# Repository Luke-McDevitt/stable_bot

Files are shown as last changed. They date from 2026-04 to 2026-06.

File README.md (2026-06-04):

# Stable-Bot 
(https://github.com/Luke-McDevitt/stable_bot)

Stewart-platform ball-balancing system: ROS 2 Kilted nodes + browser GUI
+ vision pipeline. Ships closed-loop click-to-goto control of a ball on
a 6-DOF platform with sub-mm tracking accuracy.

Links to more youtube videos coming soon!
https://youtu.be/bEEpE1CrJFA?si=kh_AgsYBSKObmkfR

## What's here

Three ROS 2 packages:

- **`stewart_bringup`** — main control node (`stewart_control_node`),
  web GUI (`gui_server.py` + `web/index.html`), level-PI inner loop,
  BALL_TRACK closed-loop controller, launch files, deploy scripts,
  digest/comparison tooling.
- **`stewart_vision`** — OAK-D camera driver, ArUco platform-pose
  estimator, parallel ball detectors (cv2 HSV + on-device YOLO),
  Kalman filter, frame-alignment calibration.
- **`jugglebot_interfaces`** — custom message and service types.

Hardware: 6× ODrive Pro motor controllers over CAN, 2× MTi-630 IMUs,
Luxonis OAK-D-PRO-AF camera, Raspberry Pi 5.

## Status

- ✅ **Demo 1 (orbit)** — implemented, tunable
- ✅ **Demo 2 (click-to-goto)** — settled at **0.5 mm median tracking
  error** (bag `20260502T025210Z_demo2`)
- ⚠️ **Demo 3 (path drawing)** — `BALL_TRACK_PATH` is stubbed, returns
  the first waypoint only. Open work.

## Getting started

Clone into a ROS 2 workspace and build:

```bash
cd ~/ros2_ws/src
git clone https://github.com/Luke-McDevitt/stable_bot.git
cd ~/ros2_ws
source /opt/ros/kilted/setup.bash
colcon build --symlink-install \
    --packages-select jugglebot_interfaces stewart_bringup stewart_vision
source install/local_setup.bash
```

Launch (Pi-side, headless):

```bash
sudo systemctl start stable_bot.service stable_bot_gui.service
```

Then open `http://stablebot.local:8080/` in a laptop browser. The
header connection dot turns green within ~5 s; arm, level, and run
demos from the panel.

For laptop / dev workflow, see
[`PI_MIGRATION.md`](stewart_bringup/docs/PI_MIGRATION.md).

## Running on the Pi — SSH & startup

**🌐 Web GUI (open in your browser):** **http://stablebot.local:8080/**
The control panel — arm, level, run demos. IP fallback:
`http://10.86.11.98:8080/`. Prefer the `.local` name; on the phone hotspot
the IP changes each session.

> **Both the laptop and the Pi must be on the same network** (your phone
> hotspot). If the GUI won't load or SSH times out, that's almost always
> the cause — reconnect both to the hotspot.

**Pi login:** user `sorak` · hostname `stablebot`

```bash
ssh sorak@stablebot.local      # preferred — mDNS resolves the current IP
ssh sorak@<current-ip>         # e.g. 10.86.11.98; changes on the hotspot
```

**Pi IP:** `10.86.11.98` (last seen). On the phone hotspot this changes
each session, so prefer `stablebot.local`. Need the current IP? Run
`hostname -I` **on the Pi** (the SSH login *banner* caches a stale IP —
ignore it; trust `hostname -I`).

**GUI rosbridge connection:** the header connection box now **auto-targets
the host you opened the page from** (`ws://<that-host>:9090`), so opening
`http://stablebot.local:8080/` connects with no IP to type. If the dot
stays red, the box is editable — set it to `ws://<current-ip>:9090`
(e.g. `ws://10.86.11.98:9090`) and click **Reconnect rosbridge**.

**Startup is two systemd services** (auto-start on boot — this *is* the
"startup script"):

| Service | What it runs |
|---|---|
| `stable_bot.service` | the ROS 2 control stack (`stewart_control_node` + vision nodes), via `ros2 launch stewart_bringup stewart_gui_launch.py` |
| `stable_bot_gui.service` | the web GUI server (`scripts/gui_server.py`) on `:8080` |

Both unit files live in [`stewart_bringup/scripts/`](stewart_bringup/scripts/)
(`stable_bot.service`, `stable_bot_gui.service`). First-time setup installs
and enables them; deploys refresh them:

```bash
# one-time, on a fresh Pi (installs deps, udev, CAN, services):
bash ~/ros2_ws/src/stable_bot/stewart_bringup/scripts/install_on_pi.sh

# deploy code changes (pull → build → restart both services → verify SHA):
~/stable_bot_repo/stewart_bringup/scripts/pi_deploy.sh
```

Day-to-day, over SSH:

```bash
sudo systemctl status  stable_bot stable_bot_gui     # are they up?
sudo systemctl restart stable_bot stable_bot_gui     # restart both
journalctl -u stable_bot.service -f                  # follow control-stack logs
journalctl -u stable_bot_gui.service -f              # follow GUI logs
```

Then open `http://stablebot.local:8080/` (or `http://10.86.11.98:8080/`)
in a laptop browser.

## Documentation

### How it works

- [`ARCHITECTURE.md`](stewart_bringup/docs/ARCHITECTURE.md) — how the
  nodes, topics, and services fit together.
- [`closed_loop_ball_demos.md`](stewart_bringup/docs/closed_loop_ball_demos.md)
  — design spec for the three demos (vision, ArUco markers, ball
  detection, KF, controllers, GUI).
- [`closed_loop_ball_demos_usage.md`](stewart_bringup/docs/closed_loop_ball_demos_usage.md)
  — operator guide: cold start, calibration, running each demo, safety.
- [`level_loop_architecture.md`](stewart_bringup/docs/level_loop_architecture.md)
  — inner level-PI loop design.

### How it got here

The journey docs are read end-to-end if you're going to touch the
controls or vision code; they explain *why* every architectural
choice was made.

- [`controls_journey.md`](stewart_bringup/docs/controls_journey.md)
  — vision rate fixes, ArUco↔IMU frame alignment, sign-convention
  derivation (2026-04-30).
- [`vision_control_tuning_lessons.md`](stewart_bringup/docs/vision_control_tuning_lessons.md)
  — vision pipeline lessons + controller architecture changes
  (2026-04-30).
- [`step_id_tuning_lessons.md`](stewart_bringup/docs/step_id_tuning_lessons.md)
  — STEP_ID plant identification, two-tilt-thresholds insight,
  cascade-bypass decision (2026-05-01).
- [`level_loop_lessons_learned.md`](stewart_bringup/docs/level_loop_lessons_learned.md)
  — runtime-vs-persistent CAN state, empirical Jacobian discovery
  (2026-04-27 → 2026-04-29).
- [`demo2_shipping_journey_2026-05-02.md`](stewart_bringup/docs/demo2_shipping_journey_2026-05-02.md)
  — the day Demo 2 shipped: empirical IK in BALL_TRACK, stiction ramp,
  position-delta exit, the winning gain set.

### Compiled cheat sheet

- [**`LESSONS.md`**](stewart_bringup/docs/LESSONS.md) — every durable
  rule from the journey docs in one terse compilation. Organized by
  topic (ODrive, vision, frames/IK, control theory, stiction, tooling,
  things that didn't work). Read this if you have 10 minutes and want
  the executive summary.

### Reference

- [`ODRIVE_PARAMS.md`](stewart_bringup/docs/ODRIVE_PARAMS.md) — every
  ODrive parameter we set, why, and the runtime-vs-persistent path.
- [`REFLASH_FIRMWARE.md`](stewart_bringup/docs/REFLASH_FIRMWARE.md) —
  ODrive firmware update procedure.
- [`PI_MIGRATION.md`](stewart_bringup/docs/PI_MIGRATION.md) — Pi 5
  headless install, hotspot setup, gotchas (apt sources, arm64
  Xsens rebuild, two-services pattern).
- [`TROUBLESHOOTING.md`](stewart_bringup/docs/TROUBLESHOOTING.md) —
  recovery recipes for rosbridge / CAN / IMU issues.
- [`NEXT_STEPS.md`](stewart_bringup/docs/NEXT_STEPS.md) — roadmap from
  the early scripted-rolling-ball state.

### Vision, latency & roadmap (2026-06 work)

- [`control_path_latency.md`](stewart_bringup/docs/control_path_latency.md)
  — **end-to-end latency trace, detection → platform moved**, every stage
  grounded in code with a **value-provenance table** (where each gain/limit
  lives). Read this to know where a number comes from.
- [`oak_latency_map.md`](stewart_bringup/docs/oak_latency_map.md) —
  vision-side latency sources + the control-path-vs-GUI-display distinction.
- [`oak_highspeed_detection_analysis.md`](stewart_bringup/docs/oak_highspeed_detection_analysis.md)
  — camera config, the focus/exposure work, and what's adopted (focus 130,
  exposure 1500 µs/ISO 3200).
- [`oak_focus_exposure_autocal.md`](stewart_bringup/docs/oak_focus_exposure_autocal.md)
  — empirical focus/exposure calibration method (the sweeps + metrics).
- [`oak_on_device_detection_research.md`](stewart_bringup/docs/oak_on_device_detection_research.md)
  — on-device detection options (YOLO re-test / fixed color blob).
- [`ball_physics_modeling_plan.md`](stewart_bringup/docs/ball_physics_modeling_plan.md)
  — data-driven ball+platform model to replace the constant-velocity
  look-forward (the next major controls project).
- [`IMPLEMENTATION_PLAN.md`](stewart_bringup/docs/IMPLEMENTATION_PLAN.md)
  — how the GUI/deploy/data-collection pieces fit together.

## Tooling

In `stewart_bringup/scripts/`:

| script | purpose |
|---|---|
| `pi_deploy.sh` | full Pi deploy: pull, colcon-build the right packages, restart both services. |
| `digest_demo_bag.py` | post-process a Demo 2/3 bag → digest.png + digest.summary.json + next-step gain recommendation. |
| `digest_step_id_bag.py` | post-process a STEP_ID bag → plant gain G_eff fit + analytic Kp/Kd/Ki recommendation. |
| `compare_demo_bags.py` | walk every digest.summary.json across a bag glob, sortable table of gains vs outcome metrics. `--diff` collapses to only the columns that varied. |
| `smooth_demo_bag.py` | offline non-causal Savitzky-Golay smoother on raw vision detections. Outputs cleaner ground-truth velocity than the live causal KF. Suitable as ML training labels. |
| `calibrate_oak.py` | OAK intrinsic + extrinsic calibration (Stage A / B / C). |

In `stewart_vision/scripts/` (focus/exposure auto-calibration — see
[`oak_focus_exposure_autocal.md`](stewart_bringup/docs/oak_focus_exposure_autocal.md)):

| script | purpose |
|---|---|
| `focus_exposure_baseline.py` | **observe-only** — snapshot the current camera config + sharpness/exposure metrics to `tuning_data/<UTC>_baseline/`. The don't-make-it-worse reference. |
| `focus_sweep.py` | step the lens through focus, measure sharpness (Tenengrad / Laplacian) per position, find the peak; **restores original focus on exit**. Repeat per `--z-mm` to build the Z→focus map. |

Top-level `repo_loc.py` counts lines of code per language across the
repo.

## Hardware reference

| Component | Detail |
|---|---|
| MCUs | 6× ODrive Pro on CAN bus (gs_usb adapter, VID:PID 1d50:606f) |
| IMUs | 2× MTi-630 over USB serial (`/dev/imu_mti630`, `/dev/imu_mti630_b`), 921600 baud, 400 Hz |
| Camera | Luxonis OAK-D-PRO-AF, USB-3 SuperSpeed, mounted on overhead arm |
| Compute | Raspberry Pi 5 (16 GB), Ubuntu 24.04, ROS 2 Kilted |
| Markers | ArUco DICT_4X4_50, 8 markers on a 120 mm-radius ring on the platform |

## Project layout

```
stable_bot/
  README.md                          ← you are here
  repo_loc.py                        ← lines-of-code counter
  jugglebot_interfaces/              ← custom msg/srv types
  stewart_bringup/
    config/
      ball_track_gains.yaml          ← BALL_TRACK PID + stiction-ramp gains
      level_gains.yaml               ← level-PI gains
      leg_limits.yaml                ← per-leg soft-limits in turns
      global_limits.yaml             ← hard tilt-rate caps
    docs/                            ← architecture + journey + lessons
    launch/                          ← stewart_gui_launch.py
    scripts/
      pi_deploy.sh                   ← deploy
      stable_bot.service             ← systemd unit (control stack)
      stable_bot_gui.service         ← systemd unit (web GUI)
      digest_demo_bag.py             ← per-bag analysis
      compare_demo_bags.py           ← cross-bag comparison
      smooth_demo_bag.py             ← offline smoother
    stewart_bringup/
      stewart_control_node.py        ← main control node (~5500 lines)
      auto_tune_node.py              ← (legacy) hill-climb auto-tuner
    web/index.html                   ← single-file Tailwind+roslibjs GUI
  stewart_vision/
    stewart_vision/
      oak_driver_node.py             ← OAK pipeline + on-device detectors
      ball_localizer_node.py         ← pixel → platform-frame mm + ArUco→IMU rotation
      ball_kf_node.py                ← Kalman filter on ball position
      platform_pose_node.py          ← ArUco-board pose
      ref_generator_node.py          ← demo target trajectories
    config/
      aruco_imu_alignment.yaml       ← Procrustes-fit rotation
      marker_layout.yaml             ← ArUco board geometry
      oak_extrinsics.yaml            ← camera-to-platform calibration
    blobs/                           ← compiled neural-net detectors for the OAK VPU
    scripts/
      calibrate_oak.py
      build_v0_blob.py
  tuning_data/                       ← bag dirs + digests, committed for traceability
  training_data/                     ← YOLO labels + cached metadata (gitignored bulk)
```

## Contributing / future work

Open work, in roughly priority order:

1. **Demo 3 (path drawing)** — implement `BALL_TRACK_PATH` ref
   generator (arc-length traversal at speed). ~30-line implementation
   per the spec.
2. **Live KF Q/R re-tuning** — use offline-smoother truth from
   `smooth_demo_bag.py` as ground truth for a Q/R grid search.
3. **Learned ball-state filter** — train a small RNN on (raw vision +
   IMU) → (smoothed position, velocity), where targets come from the
   offline smoother. Replaces or augments the live KF.
4. **End-to-end latency measurement** — automated digest analyzer
   that times from V0 detection to motor response. Lets us tune
   `control_latency_s` empirically per-config.
5. **Vision noise mitigation at the source** — better lighting,
   shorter exposure, ball-surface texture. Biggest single physical
   improvement, no code.

## License

GNU General Public License (GPL) v3

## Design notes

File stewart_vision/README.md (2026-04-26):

# stewart_vision

Vision pipeline for the Stable-Bot Stewart platform.

This package implements the OAK-D Pro AF driver, ArUco-ring platform
pose recovery, ball localization (mono projection + stereo
triangulation), the Kalman tracker, and the reference generators for
the three closed-loop ball demos defined in
`../stewart_bringup/docs/closed_loop_ball_demos.md`.

The package is **kept separate from `stewart_bringup`** so that anyone
wanting a different vision stack (RealSense, mocap, mono webcam, …)
can swap this package out without touching the controller. Topics are
the contract; node implementations are interchangeable.

## Status

**v0.1 — scaffold.** Package builds and nodes run, but most algorithm
implementations are stubs marked with TODO. The OAK driver
(`oak_driver_node`) is the most fleshed-out node and is wired against
real DepthAI for the OAK-D Pro AF.

## Build

From your colcon workspace root (the repo expected to be checked out
under `<ws>/src/stable_bot_repo`):

```bash
source /opt/ros/kilted/setup.bash
colcon build --packages-select stewart_vision
source install/local_setup.bash
```

## Run

```bash
ros2 launch stewart_vision stewart_vision_launch.py
```

Or run nodes individually:

```bash
ros2 run stewart_vision oak_driver_node
ros2 run stewart_vision platform_pose_node
ros2 run stewart_vision ball_localizer_node
ros2 run stewart_vision ball_kf_node
ros2 run stewart_vision ref_generator_node
```

## Calibration

```bash
python3 scripts/calibrate_oak.py --stage all  # first time
python3 scripts/calibrate_oak.py --stage C    # after every camera move
```

See §6 of the spec for stages A/B/C details.

## Layout

```
stewart_vision/
├── stewart_vision/         # ROS 2 nodes (Python)
├── scripts/                # Calibration + dataset + plotting tools
├── config/                 # marker_layout.yaml, ball_safety.yaml, intrinsics
├── launch/                 # stewart_vision_launch.py
└── docs/                   # README; spec lives in stewart_bringup/docs/
```

## Hardware target

Luxonis OAK-D Pro AF (auto-focus IMX378 RGB + dual OV9282 stereo monos
+ IR projector + IR illumination + Movidius Myriad X VPU). DepthAI
≥ 2.24 expected. The driver should also work on plain OAK-D and OAK-D
Pro (fixed-focus) without changes — auto-focus controls are conditional.

## Dependencies (Python)

- `depthai` ≥ 2.24 (OAK device API)
- `opencv-contrib-python` (ArUco lives in contrib)
- `numpy`
- `cv_bridge` (ROS 2 ↔ OpenCV)
- `PyYAML`

Install via apt where possible (`ros-kilted-cv-bridge`); pip the rest.

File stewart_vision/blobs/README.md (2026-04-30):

# OAK on-device V0 blobs (Phase 2B)

This directory holds compiled `.blob` files for the OAK-D Pro AF's
Myriad X VPU. They replace the host-side cv2 HSV+contour V0 detector
with on-device inference, dropping per-detection USB load from ~1.5 MB
(raw frame) to ~16 B (NNData with three FP16 floats).

## Building

The blob isn't built automatically — `blobconverter` is a Luxonis
cloud service that needs internet, and the Pi may not have torch
installed. Build from a dev machine:

```bash
pip install torch onnx blobconverter
cd ~/stable_bot_repo
python stewart_vision/scripts/build_v0_blob.py
```

That writes `stewart_vision/blobs/v0_320x180.blob`. Commit it:

```bash
git add stewart_vision/blobs/v0_320x180.blob
git commit -m "blob: rebuild V0 NN (color weights ...)"
git push
```

Then on the Pi:

```bash
~/stable_bot_repo/stewart_bringup/scripts/pi_deploy.sh
```

## Activating

The OAK driver picks `cv2` (the host detector) by default. To switch
to the NN backend, set `OAK_V0_BACKEND=nn` in the systemd override:

```bash
sudo systemctl edit stable_bot.service
```
Add:
```
[Service]
Environment=OAK_V0_BACKEND=nn
```
Save, then `sudo systemctl restart stable_bot.service`.

The `[boot]` log will show which backend was selected. If you ask
for `nn` but the blob isn't found at startup, the driver falls back
to `cv2` and logs a warning — your demos won't break.

## Tuning

Edit the color-score weights in `scripts/build_v0_blob.py` and rebuild.
The current defaults are tuned for saturated orange foam ball under
the headlamp / IKEA-panel lighting. If you change ball color or
lighting drastically:

- High-R, low-B objects: keep current weights, raise `BIAS`.
- Different hue (e.g., red vs orange vs yellow): adjust `W_G` upward
  for yellow-ish, downward for redder.
- More motion blur tolerance: lower `SCORE_FLOOR` (lets dimmer
  pixels contribute to the centroid; risk: false positives).

After rebuilding, the OAK driver picks up the new blob on next
restart — no Python source change required.

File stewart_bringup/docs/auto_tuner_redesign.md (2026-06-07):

# Auto-tuner redesign — post-mortem + ideal design

**Purpose.** We have two abandoned tuning systems (STEP-ID and the hill-climb
auto-tuner) and went back to hand-tuning. This document (1) explains what each
was, how it was used, and **why both failed**, (2) surveys what researchers
actually do, and (3) specifies the auto-tuner I'd build from scratch — with
every edge case, the integration, the accept/revert logic, the GUI sync, and
how it uses the digest to *diagnose* rather than blindly search.

Read alongside `step_id_tuning_lessons.md` and `vision_control_tuning_lessons.md`
(the primary sources) and `auto_tuning_plan.md` (the original hill-climb plan).

---

## Part 1 — Post-mortem: what they were and why both failed

### They are two fundamentally different philosophies

| | **STEP-ID** | **Hill-climb auto-tuner** |
|---|---|---|
| Philosophy | **Model-based** (white-box) | **Model-free** (black-box) |
| What it measures | Plant gain `G_eff` from open-loop tilt-step tests | A closed-loop *fitness* score per demo trial |
| How it picks gains | **Analytic** — pole-placement formula `Kp = ωn²/G_eff`, `Kd = 2ζωn/G_eff` | **Search** — perturb a gain, keep it if fitness improved |
| Targets | Repeatable fixed steps (92 mm / 170 mm) | Fixed-distance **random-direction** gotos |
| Output | One Kp/Kd/Ki recommendation | A best-found gain vector after N trials |

STEP-ID asks *"what is the plant, so I can compute the right gains?"* The
auto-tuner asks *"which gains score best, never mind why?"* They are the two
canonical families (system-identification vs derivative-free optimization).

### Why STEP-ID failed: the plant measurement isn't repeatable

`G_eff` measured **6 times in one evening on identical hardware came out 35,
224, 92, 64, 148, 564** — a 5–10× spread on an in-principle-deterministic
number. The analytic gains are a *direct function* of `G_eff`, so garbage in →
garbage out: one fit's `Kp=0.077` "drove the ball into orbital limit cycle every
trial." Three generations of the fit (parabolic → peak-velocity → regression of
`v` vs `∫θ`) only reached **30–50% CV**. The root cause was **vision noise** —
single-frame detector false-positives spiking velocity to **4,500–5,500 mm/s**
on a ball that physically tops out ~800. A single-point identification can't
average that out.

### Why the auto-tuner failed: it can't tell bad gains from bad vision

The hill-climb ran (the `auto_tune_*` sessions exist) but never beat hand-tuning.
Its documented core risk: *"Vision instability poisons fitness scores. The
auto-tuner can't separate 'bad gains' from 'bad vision'."* Concretely:
- **Random-direction targets** mean every trial has different difficulty and a
  different interaction with the vision noise → the fitness signal is buried in
  trial-to-trial variance.
- **Greedy accept/reject on a single noisy trial** (a `noise_floor` band-aid)
  means the search wanders — it accepts lucky-vision trials and rejects good
  gains that drew an unlucky trial.
- **A scalar fitness with no diagnosis** — it knows trial 12 scored 0.6, but not
  *why* (over-damped? orbiting? steady-state offset?), so it can't move
  intelligently; it perturbs blindly.
- **A pre-flight frame/alignment blocker** (§0 of the plan: "click never matches
  tilt direction") — tuning on a wrong frame just finds gains that minimize
  wrong-direction error.

### The single shared root cause

**Both failed at the *evaluation*, not the *optimizer*.** A noisy, non-repeatable,
single-shot evaluation defeats *any* tuning method — model-based or model-free.
STEP-ID's noisy evaluation was `G_eff`; the auto-tuner's was the fitness score.
Fix the evaluation and either method can work; leave it broken and neither can.

**What changed since (the board is different now):**
- **Pi under-voltage throttling is fixed** (the BEC back-feed — see
  `pi_power_throttling.md`). The Pi was likely throttling *mid-trial* during
  those sessions → dropped vision frames + timing jitter = exactly the
  non-repeatability that poisoned both. The old sessions never had this fixed.
- **The #1 documented "should-try-next" was never done: tune the KF `R`.** The
  meas-noise data now exists (`R ≈ 0.2 mm`) to dampen the velocity spikes at the
  source.
- **We now have rich step-response metrics** (overshoot / ITAE / settle / path)
  and a **validated physics model** that can serve as a digital twin.

---

## Part 2 — What researchers actually do

Three families, in rough order of sophistication:

1. **Relay feedback (Åström–Hägglund).** Replace the controller with an on/off
   relay; the loop limit-cycles at the plant's critical frequency; read the
   ultimate gain `Ku` and period `Tu` from the oscillation and apply tuning
   rules. *"One of the simplest and most robust auto-tuning techniques… applied
   in industry for 15+ years… no preliminary experiments, modeling, or external
   tools."* Strength: one short, self-exciting experiment. Weakness for us: it
   measures *one* operating point and assumes a fairly linear plant — our plant
   has stiction + the two-tilt-threshold nonlinearity.

2. **Bayesian Optimization (the modern default for expensive/noisy tuning).**
   Fit a **Gaussian-process surrogate** to the (gains → score) data seen so far,
   then pick the next gains by maximizing an **acquisition function** (expected
   improvement). It is built for *"expensive and noisy black-box optimization"* —
   the GP explicitly models observation noise, so it doesn't chase lucky trials.
   Key variants directly relevant to us:
   - **Safe / constrained BO (SafeOpt)** — restrict evaluations to a region
     that's probabilistically *stable/safe*, so the optimizer never proposes
     gains likely to send the ball orbiting.
   - **Risk-averse BO under heteroscedastic noise** (e.g. RaGoOSE) — for when
     the noise itself varies with the gains (ours does: bad gains → fast ball →
     worse vision).
   - **Early-stopping BO** — abort a clearly-bad trial early to save time.
   - **Digital-twin BO** — explore on a *model* first, spend real trials only
     where the model is uncertain. **We have a model.**

3. **Iterative/data-driven tuning (IFT, VRFT).** Estimate the gradient of a
   closed-loop cost directly from experiment data and step the gains. Powerful
   but needs cleaner signals than we have today.

**The unanimous theme:** the optimizer matters less than (a) **replicated,
low-variance evaluation**, (b) **a noise-aware surrogate** so single trials don't
mislead, and (c) **explicit safety constraints**.

Sources: [Safe contextual BO for PID tuning](https://arxiv.org/pdf/1906.12086) ·
[Safe risk-averse BO for controller tuning](https://www.researchgate.net/publication/371855392_Safe_Risk-averse_Bayesian_Optimization_for_Controller_Tuning) ·
[Early-stopping BO for controller tuning](https://arxiv.org/pdf/2501.11532) ·
[Constrained BO for cascade controller tuning](https://www.researchgate.net/publication/359250332_Safety-Aware_Cascade_Controller_Tuning_Using_Constrained_Bayesian_Optimization) ·
[Relay feedback auto-tuning — tutorial review](https://www.sciencedirect.com/science/article/abs/pii/S0959152401000257) ·
[Relay auto-tuning via iterative feedback tuning](https://www.sciencedirect.com/science/article/abs/pii/S0005109802002017)

---

## Part 3 — The ideal auto-tuner

Seven principles, each fixing a specific failure above.

### P1. Repeatable evaluation — auto-ferry to a fixed start, fixed target
*(fixes the random-target variance; finishes what STEP-ID started with "repeatable
start/end points")*

The single biggest lever. Every trial must be **identical** so the only variable
is the gains:
- **Auto-ferry**: between trials, switch to the **champion** gain set and drive
  the ball to a canonical **start** position; confirm it's settled within a
  tight band (`|err| < 8 mm`, `|v| < 20 mm/s` for 1 s) before the trial begins.
  This removes manual ball placement — the thing the operator was doing by hand
  for the model A/B — as a variance source.
- **Fixed target**: send to the **same** target each trial (the operator's
  place-and-send move, automated). Use a **small panel of 2–4 canned moves**
  (e.g. 90 mm and 170 mm, two directions) so we tune for more than one operating
  point, but each *specific* move is repeated identically.
- **Verify the start** before scoring; if the ferry didn't land the ball in the
  band, re-ferry once, else mark the trial **invalid** (not "bad").

### P2. Statistical decision — replicate, gate on CV, accept only beyond noise
*(fixes single-shot accept/reject)*

- Each gain set is evaluated with **N≥3 replicates** of each canned move.
- Compute the objective's **median and spread** across replicates. If the
  **coefficient of variation exceeds a gate (CV > 0.30)** — STEP-ID's own rule —
  **refuse to decide**: collect more replicates or flag the run as
  vision-limited. A noisy evaluation is a *measurement failure*, not a gain
  verdict.
- A challenger only beats the champion if its objective is better by **more than
  the pooled noise** (a one-sided test on the replicate distributions, not a
  single number). This is exactly what BO's noise model does automatically.

### P3. A diagnostic objective, not a blind scalar — *use the digest to know what to change*
*(fixes "can't tell why a gain set is bad"; answers "use bag digest data to be
more educated")*

We now have per-goto **step metrics** (`overshoot_pct`, `rise_s`, `settle_s`,
`steady_state_err_mm`, `settled_rms_mm`, lateral/path, `reversals`, `IAE/ITAE`).
Use them two ways:

1. **As the objective** — minimize **ITAE** (the textbook single-number step
   quality, penalizes lingering error) with **overshoot and settle as
   constraints** (e.g. "minimize ITAE subject to overshoot ≤ 20%"). Far better
   signal than the old rms/hold/calm blend.
2. **As a diagnosis that *guides* the search** — map symptoms → moves the way a
   human expert does, to give the optimizer an informed prior:

   | digest symptom | likely cause | suggested move |
   |---|---|---|
   | high overshoot, oscillatory, ITAE high | under-damped | ↑ Kd, or ↓ Kp |
   | slow rise, sluggish, never overshoots | over-damped / weak | ↑ Kp |
   | settles with a constant offset (`steady_state_err`) | no integral authority | ↑ Ki |
   | orbital limit cycle, persists regardless | `max_tilt < θ_orb` **or** vision noise | ↑ max_tilt to `max(θ_s+2.5, 8)`; check vision |
   | ball never leaves start | `Kp·err < θ_s` (stiction) | ↑ Kp / ↑ max_tilt / stiction relief |
   | large lateral wander, wrong-direction error | frame/sign/alignment | **stop** — not a gain problem |
   | `settled_rms` high but mean ~0 | vision velocity noise | tune KF `R`, not gains |

   The optimizer (BO) does the fine search; the diagnosis table provides the
   *initial direction* and catches non-gain problems (frame, vision) so we don't
   waste trials "tuning" something gains can't fix.

### P4. Noise-aware, sample-efficient optimizer — Bayesian optimization
*(replaces greedy hill-climb)*

Fit a GP to `(gain_vector → objective)` with an explicit **noise term** equal to
the measured replicate variance, and choose the next gains by **expected
improvement**. This is the documented modern standard for noisy black-box
controller tuning and is far more sample-efficient than hill-climbing (which we
can't afford many trials of). Seed it with the diagnosis-table direction from P3
and the current champion. `scikit-optimize`/`BoTorch` provide this; if we can't
put them on the Pi, run the BO step **off-board** (the Pi only runs trials and
streams results) — the optimization is cheap, the trials are the expense.

### P5. Safety — bounded, stability-screened, vision-gated, always-revertible
*(fixes "could try unstable gains"; the operator's safety bar)*

- **Hard gain bounds**, clamped before any apply.
- **Constrained/safe BO**: never *propose* gains the surrogate predicts are
  unstable (orbital). Treat "ball escaped / violent oscillation" as a **safety
  constraint violation**, recorded so that region is avoided — not just a low
  score.
- **Vision-health gate** before/within each trial: check `vcgencmd
  get_throttled == 0x0`, `/oak/health` rate, and `/ball_state` freshness. A
  trial run under throttling or a vision dropout is **invalid**, not scored.
- **Early-abort** a trial the instant the ball escapes the ring, the error
  *grows* after the goto (sign/instability), or a time budget is hit → command
  LEVEL_HOLD, ferry back.
- **Foam ring + operator kill button** (instant LEVEL_HOLD + `abort=true`) +
  **auto-halt** on K consecutive invalid/sub-floor trials.

### P6. The physics model as a digital twin — pre-screen in sim
*(uniquely available to us now)*

Before spending a *real* trial on a proposed gain set, **simulate** the move with
the fitted `ball_model.yaml` + the controller, and reject anything that's clearly
unstable or much worse than the champion in sim. This (a) keeps the ball safe
(never run a predicted-orbital gain on hardware), and (b) multiplies sample
efficiency — the documented "digital-twin BO" idea. The twin won't be exact
(that's why we still validate on hardware), but it's an excellent **safety and
triage filter**.

### P7. Champion–challenger with full provenance and atomic apply
*(answers accept / revert / GUI-update)*

- A **champion** gain set is always the current best *validated* set. A
  **challenger** must beat it on a **held-out verification panel** (canned moves
  *not* used during the search), replicated, beyond noise, **and** pass the sim
  screen, to be **promoted**.
- **Apply is atomic**: promotion calls the existing `set_control_gains` (writes
  `ball_track_gains.yaml` + updates the live dict), which already rides
  `/status` so **the GUI Gains panel inputs auto-populate** — no second code
  path. (Same mechanism that now syncs the control-method dropdown.)
- **Revert is trivial and total**: every gain set + its full metric distribution
  is logged to `tuning_data/auto_tune_<UTC>/log.jsonl`; the champion before the
  session is saved; a **"Revert to champion"** GUI button re-applies it; and
  because the yaml is git-tracked, `git checkout` is the ultimate undo. Nothing
  is overwritten without the prior value preserved.

---

## Part 4 — Every edge case

| # | Edge case | Detection | Handling |
|---|---|---|---|
| 1 | Ball escapes the ring | `/ball_state` stale > 0.5 s, or `|pos| > R` | abort trial → **invalid**, LEVEL_HOLD, ferry, retry once |
| 2 | Vision dropout mid-trial | `/ball_state` gap, `/oak/health` rate low | mark trial **invalid** (not scored); pause if persistent |
| 3 | Pi throttling during trial | `get_throttled != 0x0` | **invalid**; pause session, surface alert (should be rare post-BEC-fix) |
| 4 | Ferry fails to seat the ball at start | start band not met after re-ferry | **invalid** trial; if repeated, halt — likely champion can't hold |
| 5 | Ball never leaves start (stiction) | `max(progress) < min_travel` over the move | score = worst-feasible **with** diagnosis "below stiction"; informs ↑Kp/↑max_tilt |
| 6 | Orbital limit cycle | sustained `reversals`/speed, never settles | early-abort (safety); record region as **unsafe** for BO; check `max_tilt` vs θ_orb and vision |
| 7 | Sign / frame flip | error *grows* after goto; large lateral | **stop the session**, alert "not a gain problem" (P3 table) |
| 8 | Unstable gain proposed | sim screen (P6) or constrained BO predicts orbital | **never run on hardware**; BO avoids the region |
| 9 | High replicate variance | CV > 0.30 | **refuse to decide**; more replicates or flag vision-limited |
| 10 | Degenerate metrics (no move → no overshoot/settle) | `step_metrics` returns None | handle as invalid/worst-feasible, never NaN into the objective |
| 11 | Champion drifts (hardware change) | periodic champion re-validation worse than logged | re-baseline; warn operator |
| 12 | Optimizer proposes out-of-bounds | always | clamp to hard bounds before apply |
| 13 | Conflicting objectives (faster but more overshoot) | constraint violated | constrained objective (min ITAE s.t. overshoot ≤ cap) resolves it deterministically |
| 14 | Operator kill mid-trial | kill button | immediate LEVEL_HOLD, `abort=true`, champion preserved, state saved |
| 15 | Tuner/process crash | watchdog | champion is atomic + on disk; resume or auto-revert; never leave a half-applied gain set |
| 16 | Time / thermal budget | elapsed, `measure_temp` | graceful stop at budget; champion already safe |
| 17 | Steady-state offset vs oscillation ambiguity | `steady_state_err` vs `reversals` distinguish | diagnosis routes to Ki vs Kd — not conflated |
| 18 | Vision-noise jitter masquerading as instability | `settled_rms` high, mean ≈ 0, low reversals after smoothing | flagged as **measurement**, routes to KF-`R`, not a gain change |

---

## Part 5 — How we'll *know* it actually helped (validation)

Decisions are only trusted against a **held-out verification panel** — fixed
canned moves reserved from the search (so we measure generalization, not
overfitting to the trials we optimized on):
- Run the **old champion** and the **new challenger** back-to-back on the
  verification panel, **N replicates each, interleaved**, on a vision-healthy,
  un-throttled Pi.
- Compare the **step-metric distributions** (ITAE, overshoot, settle), not single
  runs, and require the improvement to **exceed the pooled noise**.
- This is the rigorous version of STEP-ID's verification phase + the manual model
  A/B we just did — same identical-move discipline, now replicated and
  statistically gated.

A change is "real" only if it (a) wins on the held-out panel, (b) beyond noise,
(c) without violating a constraint (overshoot/safety), and (d) the win survives a
re-test (no champion drift). Otherwise → revert to champion.

---

## Part 6 — Prerequisites before any of this runs

In strict order (each is a thing that *defeated* the old tuners):
1. **Tune the KF `R` / smooth the velocity** — kill the vision-velocity spikes at
   the source (the documented #1 unfinished item; also cuts the ~11 mm
   steady-state jitter). *Without this, every evaluation is still noisy.*
2. **Confirm vision health + click→tilt direction** on the un-throttled Pi
   (the §0 frame test).
3. **Confirm `max_tilt ≥ max(θ_s + 2.5, 8)`** so the search can't be sabotaged by
   the orbital-braking floor.
4. Only then build the tuner above — **auto-ferry + replicated + diagnostic-ITAE
   + constrained/safe BO + sim-screen + champion/challenger**.

The order matters: the optimizer is the *last* and least important piece. The old
tuners had decent optimizers and still failed, because the evaluation underneath
them was broken. Fix the evaluation first.

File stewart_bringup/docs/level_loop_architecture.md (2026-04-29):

# Stable-Bot level-loop control architecture

This is the snapshot of the level-loop architecture as of
2026-04-29 (commit `c21f7af` — last sweep at RMS 0.110°). Companion
to `level_loop_lessons_learned.md`, which explains *why* we ended up
here. This doc explains *what's running* so future-you can come back
in 6 months and read this instead of re-deriving it.

---

## Overview

The level loop closes IMU error → leg-position commands. It runs in
a single thread on the Pi 5 at 200 Hz outer-loop rate. The ODrive
controllers handle their own inner loops at 8 kHz.

```
        ┌──────────────────────────────────────────────────────────┐
        │  IMU (MTi-630 @ 400 Hz)                                  │
        │  → roll, pitch, yaw                                      │
        └──────────────────────────────────────────────────────────┘
                               │ (50 µs latency)
                               ▼
   ┌────────────────────────────────────────────────────────────────┐
   │  _level_run thread (200 Hz outer loop)                         │
   │                                                                │
   │  err = rpy_imu - level_ref                                     │
   │  err_filt = α·err + (1-α)·err_filt    [IIR, scaled by dt]      │
   │                                                                │
   │  if |err_filt| > outer:                                        │
   │       integ += -err_filt · ki · dt    [outside decay zone]     │
   │  elif |err_filt| > deadband:                                   │
   │       graduated blend of integration + decay                   │
   │  else:                                                         │
   │       integ *= integ_decay            [in deadband, full decay]│
   │                                                                │
   │  pi_out = -err_filt · kp + integ                               │
   │  corr = clamp(rate_limit(pi_out), ±max_corr)                   │
   │                                                                │
   │  rpy_cmd = current_rpy + (corr_r, corr_p, 0)                   │
   │  legs = compute_motor_targets(xyz, rpy_cmd, empirical_ik)      │
   │                                                                │
   └────────────────────────────────────────────────────────────────┘
                               │
                               ▼
   ┌────────────────────────────────────────────────────────────────┐
   │  ODriveFeeder (50 Hz cyclic on CAN, runs in its own thread)    │
   │  → Set_Input_Pos to each of 6 drives                           │
   └────────────────────────────────────────────────────────────────┘
                               │
                               ▼
   ┌────────────────────────────────────────────────────────────────┐
   │  ODrive Pro × 6 (POSITION mode, 8 kHz inner loop)              │
   │  → motor commutation, current control, encoder feedback        │
   └────────────────────────────────────────────────────────────────┘
                               │
                               ▼
   ┌────────────────────────────────────────────────────────────────┐
   │  Stewart platform (6 legs, 3 corner-pairs)                     │
   │  → physical roll, pitch, yaw of the platform                   │
   └────────────────────────────────────────────────────────────────┘
                               │
                               ▼  (closes loop via IMU)
```

Total open-loop latency from IMU sample to platform motion is
~10-15 ms. Outer-loop bandwidth is set well below that to avoid
phase-lag oscillation — KP ≈ 0.5, KI ≈ 0.5, dominant closed-loop
period ~6-9 s.

---

## Outer-loop control law (in `_level_run`)

### Gains (in `level_gains.yaml`, GUI-editable)

| gain | typical | meaning |
|---|---|---|
| `kp` | 0.5 | proportional gain (corr/err per °) |
| `ki` | 0.5 | integral gain (corr/(err·s)) |
| `deadband_deg` | 0.005-0.02 | err magnitude below which integrator decays |
| `integ_decay_outer_deg` | 0.05-0.35 | err magnitude above which decay turns off |
| `integ_decay_per_tick_at_50hz` | 0.97-0.99 | decay strength per tick at the reference rate (auto-scaled to actual loop rate) |
| `filter_alpha` | 0.3-0.4 | err IIR low-pass coefficient (auto-scaled to actual rate) |
| `rate_limit_deg_per_iter` | 0.25 | max change in `corr` per tick |
| `max_corr_deg` | 5.0 | saturation cap on `corr` |
| `use_empirical_ik` | 1 | use measured Jacobian (1) or geometric IK (0) |

### Critical features

- **Reference-rate-scaled gains**: `filter_alpha` and
  `rate_limit_deg_per_iter` are interpreted at the rate
  `LEVEL_REF_HZ = 50`. The actual loop rate (set via
  `--level-loop-hz`, default 200) scales them so the *physical*
  closed-loop response is invariant to rate. Tuning a YAML at 50 Hz
  works at 200 Hz with no edits.

- **Graduated integrator decay**: a 3-zone integrator update:
  - `|err| > integ_decay_outer_deg`: full integration, no decay
  - `deadband ≤ |err| ≤ outer`: linear blend of integration ↓ and
    decay ↑
  - `|err| < deadband`: no integration, full decay

  This eliminated the 5-second limit cycle that pure binary
  integrate-or-decay had produced.

- **Anti-windup back-calculation**: if the rate-limit or saturation
  clamp engaged, the integrator is pulled back by the deficit. Keeps
  windup bounded during step disturbances.

- **`level_ref_roll/pitch`** captured from `level_cal.json`. The IMU
  reading at the operator-defined "level" pose is the target. Doesn't
  need recalibration on every run — only after a mechanical change.

---

## Inverse kinematics: empirical Jacobian (`EmpiricalIK`)

This is the single most important thing in this doc. **The geometric
IK in `_compute_motor_targets` was wrong by 100-450%** for this
build. Replaced (for the rotational part) with a measured Jacobian.

### Architecture

`tuning_data/system_id_<UTC>/jacobian.json` contains the empirical
Jacobian from a system-ID run:

```python
J[Z][δ] = 3×6 matrix of (∂rpy / ∂leg_n) at platform pose (0, 0, Z),
          measured by perturbing each leg ±δ and reading IMU.
```

At node startup, `EmpiricalIK._load`:

1. Picks the most recent `system_id_*/jacobian.json` under
   `tuning_data/`
2. For each measured Z, averages J across deltas ≥ 0.05 (skipping
   the small-δ measurements that are stiction-noise-dominated)
3. Computes `pinv(J_z)` — the 6×3 mapping from rpy → leg deltas

At runtime, `EmpiricalIK.rpy_to_leg_deltas(z, rpy)`:

1. Linearly interpolate `pinv(J)` between bracketing measured Z
   values (clamps to nearest endpoint outside the measured range)
2. Multiply: `leg_deltas = pinv_interp @ rpy`

`_compute_motor_targets` with `empirical_ik` provided:

1. **Translation (xyz)** from geometric IK at zero rpy. `xyz` was
   never measured for system-ID, so we still trust the geometric
   model for "where the platform sits" (Z, x, y centering).
2. **Rotation (rpy)** from `pinv(J) @ rpy`. The measured response.
3. Sum + re-clamp to leg soft limits.

This hybrid (geometric translation + empirical rotation) is the IK
the level loop uses by default.

### Why this works

The geometric IK assumes:

- All 6 legs have identical mechanical advantage at each corner
- Leg-to-corner mapping matches the IK's coordinate convention
- Per-leg sign convention (which way is "extension") is uniform
- Mounting angles are exactly as designed

Reality: none of these are exactly true. The empirical Jacobian
captures the actual response — including sign flips on individual
legs vs theory, magnitude scaling per leg, and the (roll ↔ pitch)
cross-coupling that the geometric IK doesn't model.

Cost per tick: ~50 floating-point ops (linear interp + 6×3 matmul).
Cheaper than the trig-based geometric IK it replaced.

---

## Inner loop (per-drive ODrive config)

Each ODrive Pro runs its own 8 kHz inner control loop. The level
loop is the outer envelope; the inner loop handles position-tracking
to the commanded leg positions.

### Critical persistent flash settings

These must be in flash on every drive:

| param | value | path | why |
|---|---|---|---|
| `axis0.controller.config.control_mode` | 3 (POSITION) | id 378 | level loop sends Set_Input_Pos |
| `axis0.controller.config.input_mode` | 1 (PASSTHROUGH) | id 379 | no filter, no traj generator |
| `axis0.config.motor.wL_FF_enable` | True | id 305 | torque feedforward — load-bearing for tracking |
| `axis0.config.motor.current_soft_max` | 12 A | id 315 | enough current to lift the platform under tilt |
| `axis0.controller.config.vel_integrator_gain` | 0.333 | id 382 | inner-velocity I gain |
| `axis0.config.can.encoder_msg_rate_ms` | 2 | id 275 | 500 Hz encoder broadcasts |

Set persistently via `set_odrive_feedforward_via_can.py --apply
--control-mode position --input-mode passthrough --vel-integrator-gain 0.333
--wl-ff true --encoder-rate-ms 2 --current-soft-max 12.0`. This
calls `save_configuration()` per drive so the settings persist to
flash.

### Runtime self-heal in `_prepare_for_level`

Called at every Level ON. SDO-writes (runtime, doesn't touch flash):

- `control_mode = POSITION` via standard CAN cmd 0x00B
- `input_mode = PASSTHROUGH` (same cmd)
- `wL_FF_enable = True` via SDO to id 305

Plus seeds the feeder's per-leg pos targets from the current encoder
readings, so the first commanded position doesn't slam the leg
toward a stale target.

The runtime self-heal is the safety net. Even if the WebGUI or a
recalibration reverts the flash defaults, the level loop self-corrects
on every Level ON.

---

## Bag recording + diagnostics

### Per-tick: `/level_diag` LevelDiag

Published at the loop rate (200 Hz). Carries:

- IMU `roll`, `pitch`, `yaw`
- `target_roll/pitch` (the commanded reference)
- Raw and filtered errors
- Integrator state, PI output, post-clip correction
- Clip flags bitfield (which clamps engaged this tick)
- Per-leg `motor_targets`, `leg_enc`, `leg_vel`, `leg_iq_sp`, `leg_iq`
- Per-leg `axis_state` (heartbeat-derived)
- Per-leg `active_errors` (decoded bits in the analyzer)
- Per-leg `feeder_mode` (idle/pos/vel)
- `dt_actual`, `target_xyzrpy`

Recorded into rosbags via `_lr_spawn_bag` (single bag) or per-Z child
bags (auto-sweep, system-id).

### At bag start: sidecar `<bag>_notes.json`

Captured once before bag spawn. Includes:

- Outer-loop gains in effect
- `git_sha` of the running code
- `level_loop_hz` and `ctrl_period_s`
- **`inner_loop_config`**: per-drive SDO snapshot of every parameter
  in `LR_SNAPSHOT_ENDPOINTS` (current_soft_max, wL_FF_enable, gains,
  watchdog, etc.). Surfaces the asymmetry-across-drives flag in the
  digest.
- Free-text notes from the GUI
- For sysid runs: rest_rpy, rest_encoders, delta list, Z

### Offline analysis: `analyze_level_bag.py`

Per-bag `<name>_summary.json`:

- `health` block: per-leg state %, active_errors decoded, feeder_mode
  uniformity, yaw drift
- `inner_loop_config` block: per-drive snapshot + asymmetry flag
- `baseline` block: RMS, p2p, FFT peak, saturation %
- **`settling` block**: settling time, time-in-band 005/010/020
  (combined both axes), ss_mean/std/p2p over last 5 s, integrator
  drift p2p, dominant oscillation frequency

Per-bag `<name>_plots.png`:

- 6-panel diagnostic: error vs target band, corr vs saturation,
  integrator state (the wind-up smoking gun), per-leg motor target
  vs encoder, error FFT, error magnitude histogram

Sweep-level `<sweep>_overview.png`: RMS / time-in-band / settling /
saturation vs Z.

### Cross-bag comparison: `compare_bags.py`

Sectioned table comparing N bags side-by-side: gains, inner-loop
config, results. Asymmetry warnings. Markdown export. Overlay PNG of
err traces with target bands shaded.

---

## System-ID runner

`stewart_control_node._sysid_run_inner` does the empirical Jacobian
data collection:

1. Calls `_prepare_for_level` (so the same inner-loop config that
   the level loop uses is active during measurement)
2. For each commanded Z in `z_mm_list`:
    - Move platform to `(0, 0, Z, 0, 0, 0)` via geometric IK
    - Wait for settle (`_lr_wait_z_reached`)
    - Snapshot rest IMU + encoders → linearization point
    - Spawn per-Z bag for raw data
    - For each leg × δ × rep: +δ → settle → sample IMU → return →
      −δ → settle → sample → return
    - Average rpy_pos and rpy_neg across reps
3. Compute empirical + theoretical Jacobians per (Z, δ)
4. Dump to `<sysid_dir>/jacobian.json` and mirror to
   `tuning_data/system_id_<UTC>/jacobian.json`

The level loop loads the most recent `jacobian.json` automatically.
`reload_empirical_ik` cmd refreshes without restarting the node.

---

## File structure

```
stewart_bringup/
├── stewart_bringup/
│   └── stewart_control_node.py        # everything above lives here
├── scripts/
│   ├── set_odrive_feedforward_via_can.py   # configurator (persistent flash)
│   ├── dump_odrive_endpoints.py            # one-time endpoint extraction
│   ├── analyze_level_bag.py                # digest writer
│   ├── compare_bags.py                     # side-by-side comparison
│   └── ...
├── config/
│   ├── level_gains.yaml                # outer-loop gains (GUI-editable)
│   ├── leg_limits.yaml                 # per-leg soft limits + rest pos
│   └── global_limits.yaml              # bus-wide caps
├── data/
│   ├── odrive_endpoints.json           # endpoint id → name (configurator's table)
│   ├── odrive_endpoints_reference.md   # human-readable controls reference
│   └── odrive_flat_endpoints_0.6.11-1.json   # full official table for cross-check
├── docs/
│   ├── level_loop_architecture.md      # this file
│   └── level_loop_lessons_learned.md   # the journey
└── web/
    └── index.html                      # GUI
tuning_data/
├── <bag_dirs>/                         # per-bag digests + plots
├── sweep_<UTC>_sweep/                  # per-sweep dirs with per-Z child bags
└── system_id_<UTC>/                    # per-sysid runs with jacobian.json
```

---

## Performance achieved (commit c21f7af)

| metric | value |
|---|---|
| RMS roll | 0.110° |
| RMS pitch | 0.107° |
| ss_std roll | 0.0155° |
| ss_std pitch | 0.0424° |
| settling time roll | 5.18 s |
| settling time pitch | 2.42 s |
| time in ±0.10° (both axes) | 46.1% |
| time in ±0.20° (both axes) | 94.1% |

Comparison to where we started (commit a5b717d, KP=0.7 KI=0.2):

- 27× tighter steady-state std on roll
- 16× tighter on pitch
- Dominant oscillation amplitude 25× smaller
- Integrator drift 19× less

Headroom for further improvement (smaller deadband, narrower decay
zone) exists but is into diminishing returns relative to the IMU
noise floor (~0.05°). Current performance is more than sufficient
for the vision work this stack supports.

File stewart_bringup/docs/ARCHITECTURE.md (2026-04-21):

# Stable-Bot Architecture

## Process graph

```
                                               ┌──────────────────────────┐
     HARDWARE                  PROCESSES       │   BROWSER (on any host)  │
  ──────────────            ─────────────────   │                          │
                                               │   web GUI (index.html)   │
                                               │   roslibjs + fetch()     │
                                               └────────┬─────────────────┘
                                                        │ ws: 9090   http: 8080
                                               ┌────────▼─────────┐
                                               │ rosbridge (9090) │
                                               │ gui_server (8080)│
                                               └────────┬─────────┘
                                                        │ ROS topics
                  ┌──────────────┐              ┌───────▼──────────────┐
  MTi-630 #1 ────►│ xsens node   │─/base/*─────►│                      │
  MTi-630 #2 ────►│ xsens node   │─/platform/*─►│                      │
                  └──────────────┘              │                      │
                                                │  stewart_control     │
  USB-CAN ─── can0 ────────┐                    │       _node          │
                           │                    │                      │
   ┌── ODrive 0 ──┐         │                    │  (rclpy executor +   │
   ┌── ODrive 1 ──┤         │                    │   background threads)│
   ┌── ODrive 2 ──┤ <─ CAN ─┘                    │                      │
   ┌── ODrive 3 ──┤         │                    │                      │
   ┌── ODrive 4 ──┤         │                    │                      │
   ┌── ODrive 5 ──┘         │                    └──────────────────────┘
                            │                           ▲
                            └──── ODriveFeeder ─────────┤
                            └──── EncoderListener ──────┤
                                                        │
                            (optional) stall_home subproc when homing
```

## Threads inside `stewart_control_node`

| Thread | Rate | Responsibility |
|---|---|---|
| rclpy executor | event-driven | service calls, topic callbacks, timers |
| ODriveFeeder | 50 Hz | per-leg `Set_Input_Pos` (with vel_ff) or `Set_Input_Vel` |
| EncoderListener RX | blocking `bus.recv` | absorb `Get_Encoder_Estimates` (0x009), `Get_Error` (0x003), `Get_Iq` (0x014) |
| EncoderListener TX | 10 Hz / 2 Hz | RTR request encoders + errors/Iq so cyclic broadcast isn't required |
| Level loop | 50 Hz | PI control with dynamic reference + velocity feedforward integration |
| Routine player | 100 Hz | linear interpolation between keyframes, forwards to `_do_set_pose` |
| Recording sampler | 50 Hz | append a row to `telemetry.csv` during `rec`-enabled playback |
| Homing pump | blocking | stream stall_home subprocess stdout to `/homing_output` |
| CAN reset worker | on-demand | background `ip link down/up` without blocking rclpy |

## Topics

| Topic | Type | Publisher | Rate | Purpose |
|---|---|---|---|---|
| `/status` | `std_msgs/String` (JSON) | control_node | 2 Hz | armed flags, IMU freshness, level errors, routine state |
| `/leg_encoders` | `Float64MultiArray` (6) | control_node | 20 Hz | motor positions in turns |
| `/leg_currents` | `Float64MultiArray` (6) | control_node | 20 Hz | Iq_measured in amps |
| `/platform_rpy` | `Float32MultiArray` (3) | control_node | 20 Hz | IMU roll/pitch/yaw |
| `/odrive_errors` | `std_msgs/String` (JSON) | control_node | 2 Hz | per-node active_errors + disarm_reason |
| `/platform/imu/data` | `sensor_msgs/Imu` | xsens (platform) | 400 Hz | main leveling feedback |
| `/base/imu/data` | `sensor_msgs/Imu` | xsens (base) | 400 Hz | not yet used (future: wave rejection) |
| `/control_cmd` | `std_msgs/String` (JSON) | browser | on-demand | **primary action bus** (see below) |
| `/control_result` | `std_msgs/String` (JSON) | control_node | after each cmd | replies to `/control_cmd` |
| `/jog_vel_cmd` | `std_msgs/Float32` | browser | ~10 Hz while dragging | dead-man velocity slider |
| `/homing_output` | `std_msgs/String` | control_node | per line | stall_home subprocess stdout |
| `/homing_stdin_in` | `std_msgs/String` | browser | on Enter | stdin piped to stall_home |

## `/control_cmd` dispatcher

Rather than rely on ROS services (which have an intermittent discovery
bug in rosbridge on WSL2), every GUI action is a JSON message on
`/control_cmd`:

```json
{"cmd": "jog_leg", "leg": 0, "delta_turns": 0.1}
{"cmd": "set_pose", "x": 0, "y": 0, "z": 50, "roll": 0, "pitch": 0, "yaw": 0}
{"cmd": "play_routine", "name": "demo_wave", "loop": false, "record": true}
```

Every command is dispatched to the same internal methods the
equivalent ROS service handler uses, so both paths behave identically.
Replies land on `/control_result` with the same `cmd` field plus
`success` and `message`. Supported `cmd` values include:

- arm / disarm: `activate`, `deactivate`, `e_stop`, `arm_leg`
- motion: `jog_leg`, `set_pose`, `go_to_rest`, `enable_level`
- limits: `set_speed_cap`, `set_leg_current`
- errors: `read_errors`, `clear_errors`
- homing: `start_homing`, `cancel_homing`
- routines: `list_routines`, `start_recording`, `record_keyframe`,
  `clear_recording`, `save_recording`, `play_routine`, `stop_routine`,
  `delete_routine`, `generate_rolling_ball_routine`
- diagnostics: `probe_graph`, `reset_can`, `restart_ros2_daemon`

## Recovery path (when things break)

1. `scripts/reset_stewart_stack.py --launch --verify` — the go-to.
2. GUI Diagnostics panel: **View launch log**, **Hard reset stack**,
   **(Re)launch stack**, **Reconnect rosbridge**, **Restart ros2 daemon**
   — all bypass rosbridge via the `gui_server.py` HTTP endpoints.
3. `scripts/read_odrive_errors.py --clear` — direct CAN to clear ODrive
   error latches.
4. USB cycle the CAN adapter via `usbipd detach/attach` (WSL2) or
   physical replug (Pi).

## Key algorithmic choices

- **Per-leg mode feeder** — each leg independently in `pos`, `vel`, or
  `idle`. Velocity-mode legs receive `Set_Input_Vel(shared_vel)`;
  position-mode legs receive `Set_Input_Pos(target, vel_ff=dpos/dt)`;
  idle legs get nothing. Avoids fighting between pose-hold and dead-man
  jog.
- **Velocity feed-forward from finite-diff target** — collapses dynamic
  tracking error. Required when the PI gain is too low to track a
  moving reference (see the rolling-ball session notes).
- **Dynamic level reference** — PI drives `IMU_rpy → level_ref +
  current_rpy` rather than a static `level_ref`. Means commanded tilt is
  actually achieved in the world frame; routine commands aren't
  cancelled by the PI.
- **Watchdog strategy** — feeder runs at 50 Hz *before* any axis enters
  CLOSED_LOOP and continues until *after* every axis reaches IDLE. This
  prevents the 500 ms ODrive watchdog from ever firing mid-transition.
  (See `feedback_odrive_watchdog.md` memory.)
- **Homing releases the bus** — stall_home.py runs as a subprocess with
  `python -u`; the node closes its CAN socket first, then reacquires
  after the subprocess exits. Stdout is pumped byte-by-byte with a
  150 ms idle flush so `input()` prompts show up in the GUI log
  without waiting for the reply.

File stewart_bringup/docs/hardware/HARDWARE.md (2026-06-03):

# Stewart Platform — Hardware Documentation

This document covers the physical hardware for the Stable-Bot Stewart platform: electrical wiring, bill of materials, 3D-printed parts, and raw material specs. All referenced files live alongside this document unless a repo path is noted.

---

## Electrical / Power Wiring

| File | Format | Description |
|---|---|---|
| `Wiring Diagrams/Power Flow Diagram.drawio` | draw.io | Editable source for the full power flow diagram |
| `Wiring Diagrams/Power Flow Diagram.png` | PNG | Rendered export of the power flow diagram |

The power flow diagram covers the full electrical chain: power supply → ODrive controllers → motors, plus the CAN bus topology and Raspberry Pi 5 connections. Open the `.drawio` file in [draw.io](https://app.diagrams.net/) to edit.

---

## Bill of Materials

| File | Format | Description |
|---|---|---|
| `BOM For Stewart's Platform.xlsx` | Excel | Full BOM with part numbers, quantities, suppliers, and cost |
| `CF Tubes for legs.txt` | Text | Carbon fiber tube lengths and specs per leg (6 legs total) |
| `inline-motor-linear-actuator-bom.webp` | Image | Reference spec sheet for the inline-motor linear actuator |

### Carbon Fiber Tube Summary (from `CF Tubes for legs.txt`)
- **Short tubes:** 0.11 m × 4 per leg, 8 mm OD / 6 mm ID (26.4 m total)
- **Long tubes:** 0.37 m × 3 per leg, 8 mm OD / 6 mm ID (6.66 m total)
- **Large tubes:** 0.40 m × 1 per leg, 16 mm OD / 14 mm ID (2.4 m total)

---

## 3D-Printed Parts

All STL files are in `Printing files/`. Use Git LFS when committing these to the repo — the full set is ~135 MB.

### Leg Assembly (`Printing files/Leg Assem/`)
One full leg comprises:
- `Leg_Base_Piece_V3_InlineMotor.stl` — motor mount base
- `MotorHousing_InlineMotor_V2_BoltedCFGrippers.stl` (×2) — upper/lower motor housing
- `UpperLeg_BearingBlock_Main_V4_InlineBearings_BoltedCFGrasper.stl` — bearing block
- `UpperLeg_Bearing_Inner.stl` — inner bearing race
- `StringPulley_V2_FlatProfile.stl` — string pulley
- `Pulley.stl` + `Pulley_Spacer.stl` — drive pulley set
- `SUJ_Inner.stl` + `SUJ_Outer.stl` + `SUJ_Leg_Cap.stl` — spherical universal joint (SUJ) components
- `CFTube_Bottom_EndCap_V4_For_SUJ.stl` — CF tube bottom end cap
- `Magnetic_Joint_Ball.stl` + `Magnetic_Joint_Magnet.stl` — magnetic joint pair
- `TPU_Bearing_Sleeve.stl` — TPU bearing sleeve (flexible filament)
- `M3_to_6mm_Spacer.stl` — spacer
- `Leg Base Attachment.stl` — base attachment bracket

### Revised End Caps (`Printing files/New End Caps & Reprints/`)
Replaces earlier end cap design with improved bearing seat:
- `Top end cap 128 density with better bearing seat_6x.stl`
- `bottom endcap 128 density_6x.stl`
- `SUJ_Outer_3x.stl`

### Full Platform Assembly
- `Printing files/JBV4 Assem(1)/JBV4 Assem.obj` + `.mtl` — complete Jugglebot V4 platform mesh (OBJ format, ~490 MB, use Git LFS)
- `Printing files/JBV4 Assem.zip` — zip of the above

### McDevitt Print Sets
Organized print batches for building one complete platform:
- `Printing files/McDevitt To Be Printed/` — first batch (1 leg worth)
- `Printing files/Rest of Prints for Stewarts McDevitt/` — remainder (×5 legs, ×5 platform nodes)

---

## Configuration Notes

- `Need 6 legs in this configuration.docx` — diagram and notes on the leg arrangement pattern required for the Special 6-6 Stewart platform geometry

---

## Related Repo Paths

When committing these hardware assets to `stable_bot`, suggested destinations:

```
stewart_bringup/docs/hardware/
├── HARDWARE.md                          ← this file
├── Power Flow Diagram.drawio
├── Power Flow Diagram.png
├── BOM For Stewart's Platform.xlsx
├── CF Tubes for legs.txt
├── inline-motor-linear-actuator-bom.webp
└── cad/
    ├── Leg Assem/                       ← STL files (Git LFS)
    ├── New End Caps & Reprints/         ← STL files (Git LFS)
    ├── McDevitt To Be Printed/          ← STL files (Git LFS)
    └── Rest of Prints for Stewarts McDevitt/  ← STL files (Git LFS)
```

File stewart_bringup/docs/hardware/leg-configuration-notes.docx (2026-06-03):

Need 6 legs in this configuration:
https://www.pi-usa.us/en/tech-blog/gyroscopic-stabilization-of-a-hexapod


To do the linear actuation, we want waterproof actuators such as
https://www.ultramotion.com/industries/underwater-subsea-linear-actuator/
Or
https://www.2g-eng.com/subsea-products/linear-actuators/

To allow for the turret to be rotated on the platform some kind of basic turntable with electrical slip couplings must be used

To allow for up / down aiming the turret must also have another degree of freedom of up / down rotation (more slip couplings)

Use object detection for aiming and then use some kind of depth mapping / depth sensing to find how far away target is

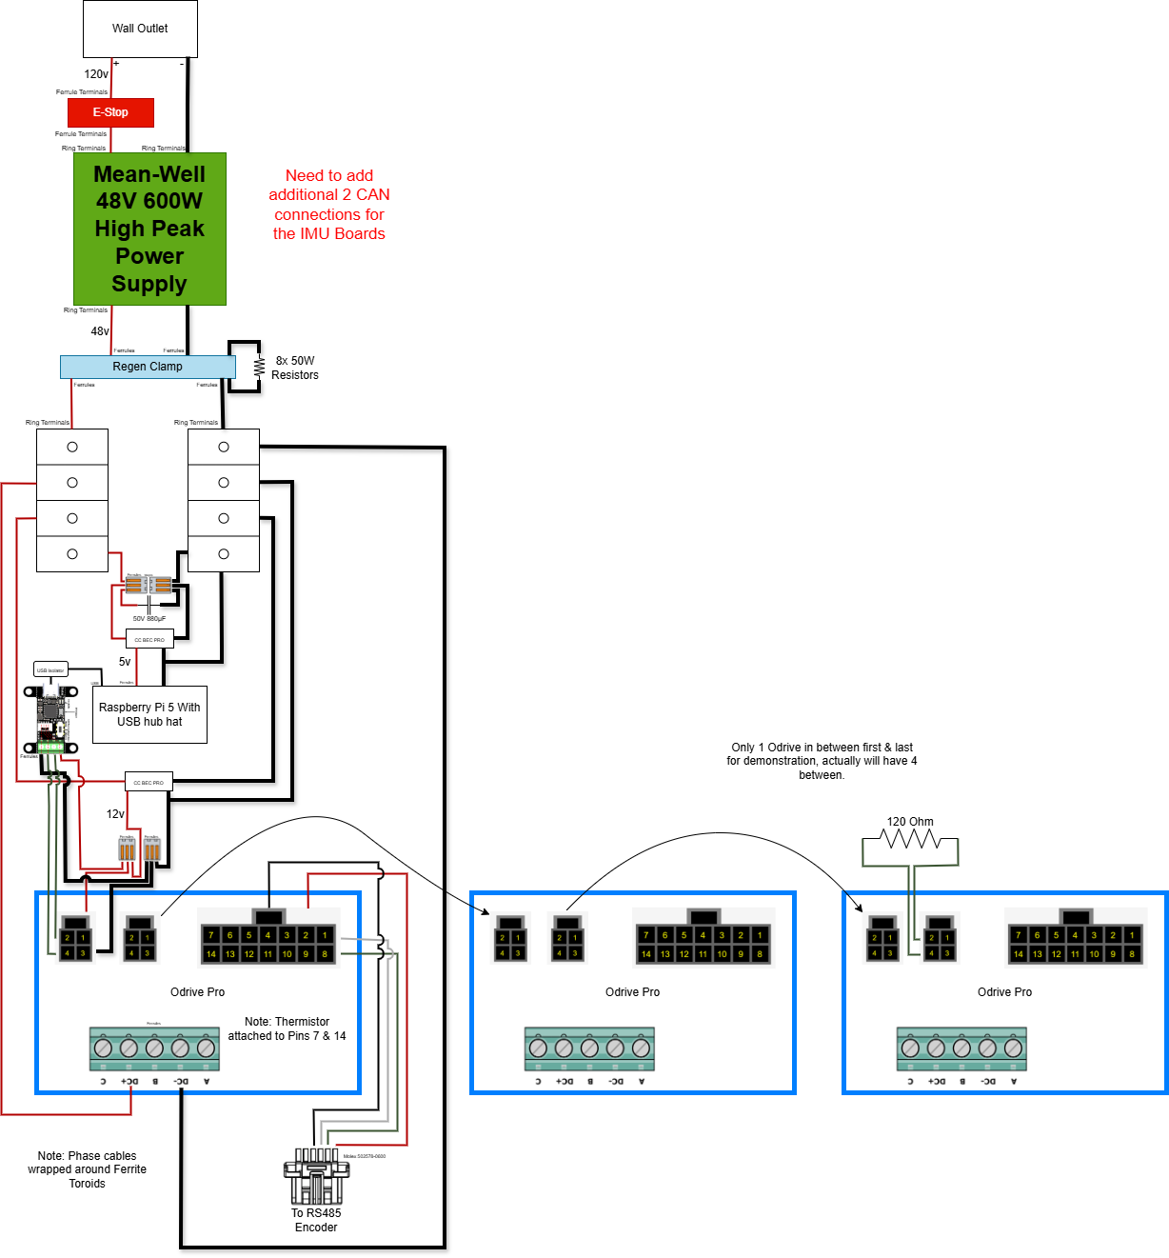
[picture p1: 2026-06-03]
stewart_bringup/docs/hardware/Power Flow Diagram.png

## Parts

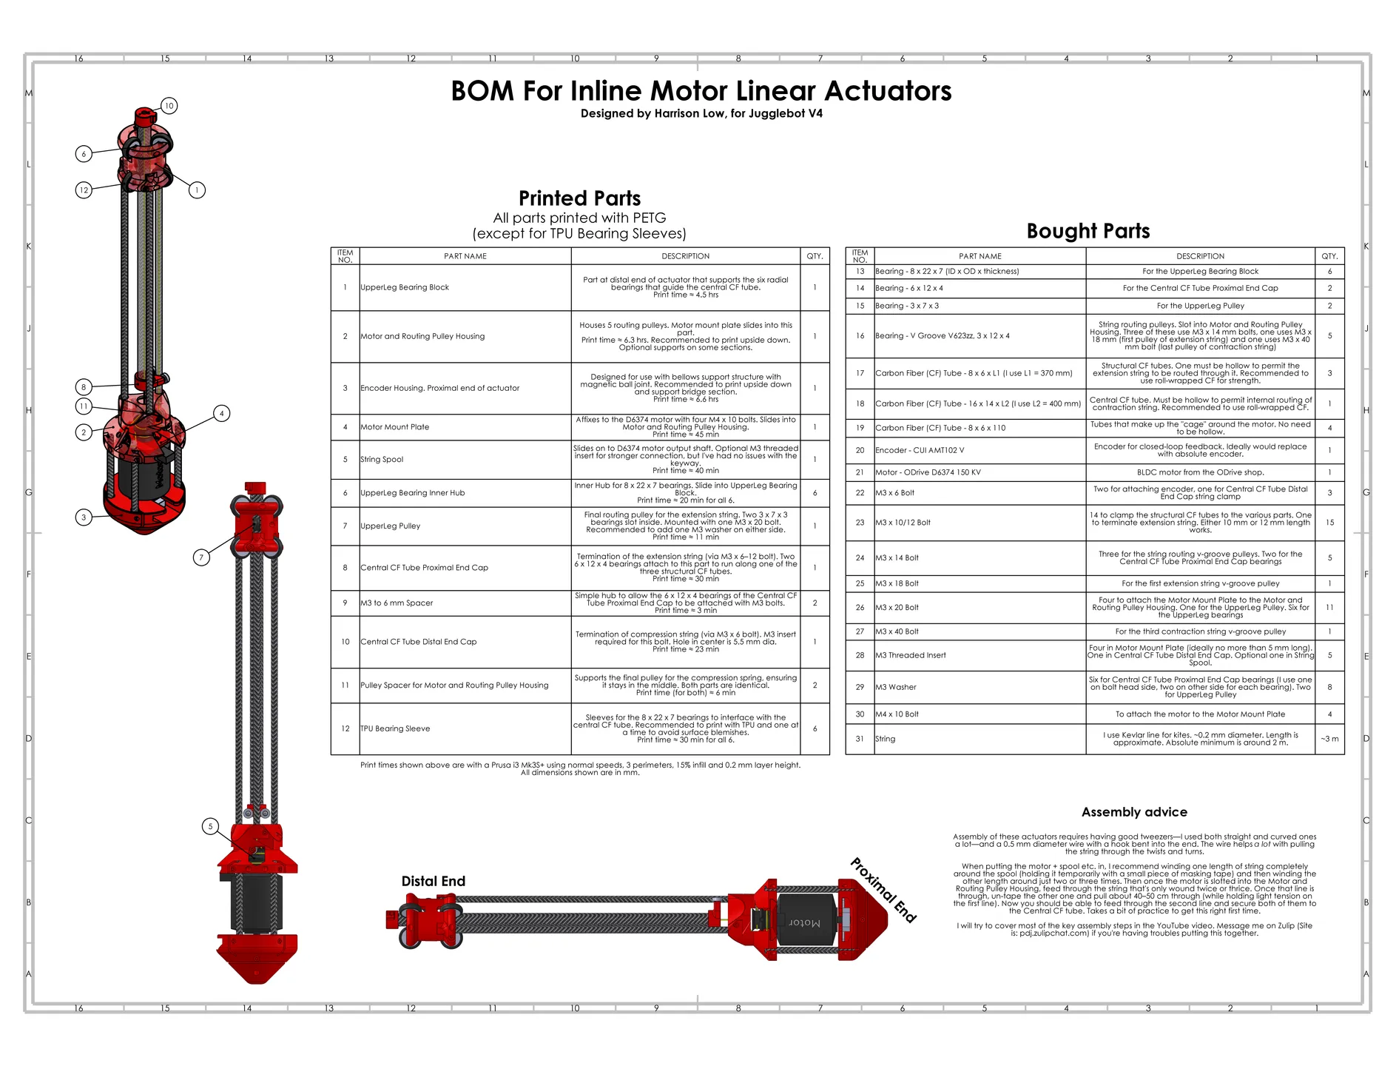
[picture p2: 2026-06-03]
stewart_bringup/docs/hardware/inline-motor-linear-actuator-bom.webp

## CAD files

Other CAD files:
stewart_bringup/docs/hardware/cad/Rest of Prints for Stewarts McDevitt/Top Motor assembly_5x.stl
stewart_bringup/docs/hardware/cad/Leg Assem/Leg Assem - Main Part.stl
simulations/assets/puma/Revolute-to-end-effector-v1_Revolute-to-end-effector.stl
stewart_bringup/docs/hardware/cad/Leg Assem/Leg Assem - SUJ_Leg_Cap.stl
stewart_bringup/docs/hardware/cad/McDevitt To Be Printed/Leg Assem Parts - Pulley.stl
stewart_bringup/docs/hardware/cad/New End Caps & Reprints/bottom endcap 128 density_6x.stl
stewart_bringup/docs/hardware/cad/Rest of Prints for Stewarts McDevitt/Leg Assem Parts - Pulley_Spacer_30x.stl
simulations/assets/puma/Base-with-revolute-v1_Base-with-revolute-on-it.stl
stewart_bringup/docs/hardware/cad/Leg Assem/Leg Assem - M3_to_6mm_Spacer.stl
stewart_bringup/docs/hardware/cad/McDevitt To Be Printed/Leg Assem Parts - StringPulley_V2_FlatProfile.stl
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

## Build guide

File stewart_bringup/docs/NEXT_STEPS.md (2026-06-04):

# Next Steps — Closed-loop rolling-ball demo with vision

**Current state (2026-04-22)**: the platform can execute a *scripted*
rolling-ball routine (open-loop — the trajectory is precomputed and the
controller doesn't know where the ball actually is). Professor's
assignment requires a real closed loop. Extra-credit target: tilt the
platform so the ball can be driven to any requested (x, y) point on the
disk.

Hardware has been purchased and the plan is now concrete.

> **Status update (2026-06-03)** — Milestones 1–6 are done and the
> click-to-goto closed loop (Demo 2) has shipped (settled ball at
> ~0.5 mm median tracking error). Milestone 7 (click-to-move / live
> re-targeting) is in active operator tuning. Everything from here down
> to the Milestones list is the original 2026-04-22 plan, kept for
> context — the architecture it describes is now built and live in
> `stewart_vision/` + `stewart_bringup/`. The next *foundational*
> controls work is **[Phase 2 — Data-driven ball + platform forward
> model](#phase-2--data-driven-ball--platform-forward-model-look-forward-upgrade)**
> at the end of this doc: replacing the constant-velocity "look-forward"
> the controller uses for latency compensation with an empirical,
> data-driven physics model.

## Hardware

- **Luxonis OAK-D-PRO-AF** — stereo + 12 MP color + IR dot projector +
  Movidius Myriad X VPU. The VPU runs ball detection onboard, so the Pi
  never touches raw frames. USB3-powered from the Pi (put it on a
  *different* USB3 port than the CAN adapter — they share a bus).
- **4-ft aluminum extrusion / bar** for an overhead-angled camera mount,
  rigid to the world (not to the platform). A shallow oblique angle
  (~30–45° off vertical) lets the camera see the ball all the way to
  the rim without the platform edge hiding it.
- **Matte vinyl sticker paper** (8.5×11, inkjet-compatible) for the
  ArUco ring. Matte is critical — glossy vinyl specular-highlights under
  the OAK's IR projector and ruins corner detection.

## Platform-pose tracking: ArUco ring on the top plate

Rather than trying to infer the platform's pose from each leg's encoder
(which is valid but sensitive to any compliance or backlash), we use
vision directly: a ring of ArUco markers around the platform's top
surface. The camera solves for the ring's pose every frame, giving the
disk's orientation and translation in the camera frame. The ball's
image-plane position is then projected onto that plane.

**Spec**:
- Dictionary: `DICT_4X4_50` (bigger inner cells → reliable from an
  oblique overhead view).
- ~6–8 markers arranged on a circle of radius ~120 mm (just inside
  the platform edge), 50 mm per side.
- All markers at the same orientation (local +y = platform +y) — makes
  the board layout trivial.
- Detected as an **ArUco board** (`cv.aruco.estimatePoseBoard`), not as
  independent markers. The board solver uses all visible markers jointly
  → sub-pixel corner refinement → much better pose than averaging.
  Partial occlusion (ball over a marker, leg shadow) is handled gracefully
  as long as ≥ 3 markers stay visible.

**Print workflow**: the generator script
(`scripts/generate_aruco_ring.py`) produces the ring image, splits it
into 8.5×11 pages with registration marks and a `marker_layout.yaml`
describing every marker's (id, x_mm, y_mm). Print at 100 %, cut, align,
stick. The YAML is what the vision node feeds to `estimatePoseBoard`.

## Ball detection: onboard the OAK's VPU

Do not try to detect the ball on the Pi — you'll burn CPU decoding
1080p frames that you then throw away. Run a small detection pipeline
on the OAK itself; publish only the ball's (cx, cy) and a detection
confidence to the Pi.

Two viable approaches:

1. **Color threshold on a known-color ball** — paint / tape a ball in a
   color that doesn't appear anywhere else in frame (a saturated orange
   works well against carbon fiber and black markers). Convert to HSV on
   the VPU, threshold, biggest contour, centroid. ~1 ms inference, ~0
   training effort. This is where I'd start.
2. **YOLO-nano trained on ~100 labeled frames** — drop-in robustness to
   lighting and clutter. The OAK's Myriad X runs YOLOv5-nano at >30 FPS.
   Worth doing once the color-threshold version is working, if robustness
   matters.

Either way, publish `/ball_pixel` (cx, cy, confidence) from the camera.
The node on the Pi takes the image-plane point + the ArUco board pose +
camera intrinsics, and projects the pixel ray onto the platform plane to
get (x_mm, y_mm) on the disk. That's `/ball_xy`.

## Package layout

New ROS 2 package `stewart_vision` (kept separate from `stewart_bringup`):

```
stewart_vision/
  stewart_vision/
    oak_driver_node.py       # starts OAK pipeline, publishes /ball_pixel
    platform_pose_node.py    # subscribes to OAK image, solves ArUco board pose, publishes /platform_pose
    ball_projector_node.py   # combines /ball_pixel + /platform_pose → /ball_xy
  config/
    marker_layout.yaml       # generated by generate_aruco_ring.py
    oak_intrinsics.yaml      # from OAK factory calibration
  launch/
    stewart_vision_launch.py
```

The existing `stewart_control_node` gains a new level-loop mode
`BALL_TRACK` that subscribes to `/ball_xy`, runs a 2-axis PID on
(x, y) error vs. a `/ball_ref` target, and writes tilt (roll, pitch)
commands. For the extra-credit mode, `/ball_ref` comes from a click on
the GUI's live camera feed; for the base demo, it's the precomputed
rolling trajectory.

## Latency budget

Everything must close in under ~30 ms to avoid wobble:

| Stage | Target |
|---|---|
| OAK exposure + on-chip detection | ≤ 15 ms |
| USB3 → Pi + ROS topic hop | ≤ 3 ms  |
| `/ball_pixel` + pose → `/ball_xy`  | ≤ 2 ms  |
| Control loop tick (already 50 Hz)  | ≤ 20 ms |
| **Total** (worst case) | **≤ 40 ms** |

Measure this before tuning gains — if the budget is blown, lowering PID
gains just hides the instability.

## Milestones

1. ✅ **Print + stick the ArUco ring.** `generate_aruco_ring.py` →
   `marker_layout.yaml`, detected as an ArUco board.
2. ✅ **OAK-D driver up.** `oak_driver_node.py` streams and runs
   detection on the VPU; the Pi never decodes raw frames for tracking.
3. ✅ **Ring pose working.** `platform_pose_node.py` publishes platform
   pose; verified against the IMU to within ~1°.
4. ✅ **Ball detection on VPU.** cv2-HSV V0 backend @ ~27 Hz arrival.
   (YOLOv6n/v8n V1 also built but worse under fast motion — see
   `step_id_tuning_lessons.md` §3.)
5. ✅ **Ball-in-disk-frame.** `ball_localizer_node.py` → `/ball_xy_mono`;
   `ball_kf_node.py` fuses to `/ball_state` (px, py, vx, vy) @ 100 Hz.
6. ✅ **Closed-loop ball-centering.** `BALL_TRACK` PID commands tilt
   directly (cascade-bypass — level-PI disabled on entry). Velocity
   sanity gate + stiction relief + latency lookahead all live.
7. ⏳ **Click-to-move (extra credit).** `BALL_TRACK_GOTO` /
   `BALL_TRACK_PATH` modes exist; live operator tuning in progress.
8. ☐ **Trajectory tracking (base demo).** `BALL_TRACK_TRAJECTORY` +
   `ref_generator_node` scaffolded; gated on the Phase 2 predictor for
   clean tracking at speed.

## Open questions / decisions to make before writing code

- **Camera mount angle**: straight-down or oblique? Oblique (30–45°) lets
  you see the ball at the rim, but the projection math is uglier. Pick
  one and commit before calibrating — recalibrating every time the mount
  moves is expensive.
- **Coordinate frame**: report `/ball_xy` in platform-frame mm (rotates
  with the disk) or world-frame mm (fixed)? Platform-frame is what the
  controller wants.
- **When does `/ball_xy` become stale?** If the ArUco ring is fully
  occluded, the last good pose is held, but for how long? Default:
  drop to level-only mode after 500 ms of no detection.

---

# Phase 2 — Data-driven ball + platform forward model (look-forward upgrade)

**Added 2026-06-03.** The next foundational controls task. It adds no
hardware — it replaces the *model* the controller uses to predict the
ball during the latency window.

> **Deep dive:** the full research-grounded physics-model hierarchy and
> the ROS-bag data-collection battery (breakaway-vs-tilt-rate, coasting,
> persistent-excitation sweeps, ArUco coverage grid, every loggable
> parameter) live in
> [`ball_physics_modeling_plan.md`](ball_physics_modeling_plan.md).
> This section is the summary.

## What the "look-forward" is today

BALL_TRACK runs ~100 ms behind reality (OAK exposure + USB + KF +
control tick). So the controller doesn't chase where the ball *was*,
`_ball_track_run` extrapolates the ball forward by one latency window
before computing error:

```python
# PID branch (stewart_control_node._ball_track_run)
ex_lead = ex + edot_x * control_latency_s     # control_latency_s ≈ 0.10 s
ey_lead = ey + edot_y * control_latency_s
# bang-bang FSM branch (mirror)
px_lead = px + vx * latency_s
py_lead = py + vy * latency_s
```

This is a **constant-velocity straight-line extrapolation** — it assumes
the ball keeps its current KF velocity for the entire 100 ms. The KF
behind it (`ball_kf_node.py`) is *also* constant-velocity: state
`[px, py, vx, vy]`, `F` is pure kinematics, and Q/R are still the
untuned placeholders (σ_a = 5000 mm/s², R = 1 mm).

## Why that's not good enough

During the latency window the ball is not coasting — it is on a plate
the controller is actively tilting. The true plant (already written down
in `_ball_physics.py`) is:

```
ẍ = α·g·sin θ  −  (rolling / viscous damping)  −  (stiction dead-zone)
α = 5/7 foam (solid sphere),  3/5 ping-pong (hollow)
```

At the tilts BALL_TRACK commands, `α·g·sin θ` is a real acceleration the
straight-line model ignores completely; so is friction deceleration near
the target and the stiction dead-zone near zero velocity. The prediction
is therefore wrong exactly on the accelerating / decelerating transients
where look-forward matters most — part of why fast trajectories still
orbit and overshoot (see `step_id_tuning_lessons.md`). Constant-velocity
is the easy 80 %; getting the controls *perfect* needs a predictor that
knows what the plate is doing.

## The upgrade: fit the forward model from logged data

Instead of feeding textbook constants into `α·g·sin θ`, **fit the
effective dynamics from our own bags** and integrate *that* forward over
the latency window using the tilt the controller actually commanded:

```
x̂(t + Td) = ∫ f_θ( ball_state, commanded_tilt(τ) ) dτ      over [t, t + Td]
```

where `f_θ` is the fitted model. Two candidate forms (open decision —
start gray-box):

| Form | Model | Trade-off |
|---|---|---|
| **Gray-box (do this first)** | Keep the physics skeleton `ẍ = G_eff·sinθ − c·ẋ − stiction(θ_s, μ_s)`; fit `G_eff` (effective α·g, *not* the nominal 5/7), damping `c`, breakaway `θ_s`. | Interpretable, few params, and **STEP_ID already estimates exactly these** (`G_eff`, `θ_s`, `μ_s`). Direct extension of existing code. |
| **Black-box** | Small regression / tiny NN: recent `(state, tilt)` history → Δposition over Td. | Captures un-modeled effects (leg backlash, IK error, Z-coupling) but is data-hungry and opaque; vision noise makes it fragile. |

Gray-box is the obvious starting point: it generalizes `_ball_physics.py`
(swap nominal α for fitted `G_eff`) and reuses the STEP_ID Gen-3
regression methodology — `v(t)` vs `∫θ dτ`, median-filtered position,
3σ outlier rejection (`step_id_tuning_lessons.md`, "Plant ID
methodology").

## Where it plugs in

1. **Predictor (primary).** Replace the `x_lead = x + v·Td` lines in
   `_ball_track_run` with a forward-integration of `f_θ` over the
   commanded-tilt history. The controller already knows its own command
   stream — keep a short ring buffer of issued tilts so the integration
   uses the real `θ(τ)`, not a single instantaneous value.
2. **KF → EKF (optional; spec §8 / `ball_kf_node.py` TODO).** Fold `f_θ`
   into the motion model so prediction is dynamics-aware *between*
   measurements. Shrinks Q and keeps `/ball_state` sane through vision
   dropouts (the dominant failure mode). Do this only if the predictor
   swap alone doesn't settle Demo 2.

Gate the new predictor behind a runtime flag, mirroring the existing
`use_empirical_ik` A/B toggle, so the constant-velocity baseline stays
one switch away during tuning.

## Data pipeline (mostly already built)

- **Record** — `bag_recorder_node.py` already logs `/ball_state`,
  commanded tilt, IMU-actual tilt, and `/oak/latency_ms`. Make sure
  every BALL_TRACK + STEP_ID run captures all four.
- **Clean the target** — `smooth_demo_bag.py` is an offline *non-causal*
  velocity estimator; use it to produce the clean "ground-truth" future
  position each causal prediction is scored against. Vision noise is the
  bottleneck — never fit against raw single-frame velocity.
- **Fit** — new `scripts/fit_ball_forward_model.py`, ingesting STEP_ID +
  demo bags, emitting `config/ball_forward_model.yaml` (the analog of
  `step_id_recommendation.json`).
- **Validate** — prediction error *at horizon Td* on held-out bags
  (model-predicted position vs smoothed actual), reported against the
  constant-velocity baseline. The win condition is lower horizon error,
  not lower fit residual.

## Milestones (Phase 2)

1. ☐ Confirm logging: every relevant bag carries commanded tilt + IMU
   tilt + `/ball_state` + measured latency. Measure latency for real
   with `measure_detector_latency.py` instead of assuming 0.10 s.
2. ☐ Offline gray-box fit → `ball_forward_model.yaml` (`G_eff`, `c`,
   `θ_s`) using the robust STEP_ID regression.
3. ☐ Horizon-error validation on held-out bags; quantify the improvement
   over constant-velocity.
4. ☐ Online predictor swap in `_ball_track_run`, behind a flag; A/B on
   Demo 2.
5. ☐ (Optional) EKF motion model in `ball_kf_node.py`; tune Q/R from the
   same bags.
6. ☐ Re-run STEP_ID verification + Demo 2; confirm reduced orbital
   limit-cycling and tighter settle.

## Open decisions (Phase 2)

- **Gray-box vs black-box** — start gray-box; revisit only if structured
  residuals remain after fitting.
- **Predictor-only vs predictor + EKF** — ship the predictor swap first;
  it's cheaper and the KF change is riskier.
- **One global fit vs Z-parameterized** — `G_eff` may vary with platform
  Z (`step_id_tuning_lessons.md` open-question #6). All STEP_ID runs so
  far were at Z = 80 mm, but demos run at Z = 30–50 mm. Fit at the demo
  Z, or parameterize on Z.
- **Horizon** — fixed 100 ms vs per-tick from `/oak/latency_ms`. Per-tick
  is more correct if latency jitters.
- **Tune KF R first?** — `step_id_tuning_lessons.md` open-question #2:
  damping vision spikes at the KF input may matter more than the model
  form. Probably do this before / alongside the fit.

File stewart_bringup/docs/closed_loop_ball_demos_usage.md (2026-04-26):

# Closed-Loop Ball Demos — Operator Usage Guide

How to USE the system. The companion design spec at
`closed_loop_ball_demos.md` covers WHY each piece exists.

Read this when you're about to drive the robot. Read the spec when
you want to know why a particular choice was made.

This guide assumes the v9 spec / v8.1 GUI scaffold is live on the Pi.
The cold-start sequence below mirrors the existing
`stable_bot_startup.txt` reference card; everything else is new with
the vision pipeline.

---

## 0. Pre-flight before pushing v8.1 GUI to the Pi

Run these once after pulling the latest commit, before walking up to
the robot:

- [ ] `git pull` on the Pi to grab the new GUI + nodes:
  ```bash
  ssh sorak@stablebot.local
  cd ~/<your-workspace>/src/stable_bot_repo && git pull
  ```
- [ ] Build the new package (intrinsics + extrinsics calibrators,
  ArUco helpers, calibration node, bag recorder):
  ```bash
  cd ~/<your-workspace>
  source /opt/ros/kilted/setup.bash
  colcon build --packages-select stewart_vision
  source install/local_setup.bash
  ```
- [ ] Restart the GUI service so the new index.html is served:
  ```bash
  sudo systemctl restart stable_bot_gui.service
  ```
- [ ] Open `http://stablebot.local:8080/` from your laptop. Confirm:
  - Vision Debug + Calibration panels appear at the top of the LEFT column.
  - Demo 1 / 2 / 3 panels appear at the top of the MIDDLE column.
  - Existing controls (Status / Arming / Encoders / Jog / Pose / Homing /
    ODrive errors / etc.) still work unchanged.
  - The 3D Viewer panel is collapsed at the bottom of the middle
    column (placeholder; v9 implementation).
- [ ] If the OAK isn't plugged in yet, the page will still load —
  `oak_driver_node` will log a fatal but the existing control
  stack is unaffected. Plug in the OAK and
  `sudo systemctl restart stable_bot.service` to bring vision online.
- [ ] Run the Stage-C calibration flow (§2). Confirm
  `oak_extrinsics.yaml` gets written.
- [ ] **Pick the ball type** in the GUI header dropdown ("Ball:
  foam" vs "Ball: ping-pong") to match the physical ball you're
  about to use. Persists across reloads. Affects PID feedforward
  (α=5/7 solid vs 3/5 hollow) and is captured in every bag.
- [ ] Optional: run the unit tests on your laptop before pushing:
  ```bash
  cd ~/stable_bot_repo/stewart_vision
  python3 -m pytest test/ -v
  ```
  35 should pass; up to 3 cv2-aruco-dependent tests will skip if
  opencv-contrib isn't installed in the env you're testing from.

Once all checkboxes pass, you're at step 1 of the iteration ladder
in spec §16.

---

## 1. Cold start (≈ 5 minutes from power-off to first demo)

### 1.1 Pre-flight check

- [ ] Pixel 9 hotspot is on; laptop is connected to it.
- [ ] Stable-Bot sits on a stable, level workbench.
- [ ] OAK-D Pro AF is on its camera arm, pointed at the platform,
  cable plugged into the Pi's **blue USB-A 3.0** port (NOT
  USB-C — that's power-only on the Pi 5).
- [ ] Both MTi-630 IMUs and the USB-CAN adapter are plugged in.
- [ ] No ball on the platform yet.

### 1.2 Power on

1. Plug Stable-Bot's power into the wall.
2. Wait ~45 seconds for the Pi to boot. Two systemd services
   auto-launch:
   - `stable_bot.service` — ROS 2 nodes (control, IMU, vision)
   - `stable_bot_gui.service` — gui_server.py + rosbridge_websocket

### 1.3 Connect the laptop browser

1. Open `http://stablebot.local:8080/` in your browser.
   (Hotspot mDNS sometimes flakes — if mDNS doesn't resolve,
   look up the IP in the Pixel hotspot's "Connected devices"
   page next to `stablebot` and use `http://<pi-ip>:8080/`.)
2. The page should load. The header connection dot turns green
   within ~5 seconds.
3. The header WS URL field defaults to `ws://stablebot.local:9090`.
   It is sticky (last successful URL is remembered). If you needed
   to use a hotspot IP for HTTP, also override the WS URL to match.
4. If you see "no /status received" for > 10 seconds, click the red
   **RESET** button in the Diagnostics panel. The whole stack
   restarts; wait 30 seconds and try again.

### 1.4 Arm + level the platform

1. **Arm** — click the green Arm button (left column, Arming
   panel). All six legs go to CLOSED_LOOP_CONTROL.
2. **Go to rest** — settles the top plate to neutral pose.
3. **Level ON** — IMU-based level loop holds the plate flat
   (within ~0.2°).

If anything misbehaves (Errors panel turns red, motors won't arm),
use **Diagnostics → Hard reset stack**. That kills and re-launches
everything from a clean slate.

---

## 2. Camera calibration (Stage C only — once per camera arm move)

The OAK ships **factory-calibrated** for intrinsics and stereo
extrinsics, and the GUI uses those by default. The only thing you
re-run is **Stage C** — the camera-to-platform pose — and only when
the camera arm physically moves.

If the camera hasn't moved since your last calibration, skip this
section.

### 2.1 Pre-flight

- [ ] Platform is leveled (Level ON; confirm IMU readout shows
  roll and pitch within ±0.1°).
- [ ] ArUco ring sticker is intact, all 8 markers visible from the
  current camera angle.
- [ ] Lighting is even on the ring (no glare from the IR projector).

### 2.2 Capture + solve in the GUI

1. In the **Vision Debug** panel (left column, top), expand the
   **Calibration (Stage C)** sub-panel.
2. Confirm the live left-eye feed shows the ArUco markers with
   green corner overlays drawn on each. The "markers visible"
   count should read 8 / 8 (or at minimum 3 / 8 to proceed).
3. Click **Capture frame**. A toast reports e.g. "frame 1
   accepted — 8/8 markers, reproj 0.74 px". If reprojection > 2 px
   or markers < 3, the frame is rejected; adjust angle/lighting
   and retry.
4. (Optional) capture 2-3 more frames at slightly varied platform
   states for better averaging — not necessary on a stable
   leveled platform but doesn't hurt.
5. Click **Solve**. The system runs `cv2.aruco.estimatePoseBoard`
   over the captured frames, averages, and writes
   `oak_extrinsics.yaml` into the package's share directory.
6. Confirm the toast: "oak_extrinsics.yaml written — 1 frame,
   mean reproj 0.74 px. Buffer cleared."

You're done. The platform_pose node picks up the new extrinsics
on its next pose update; no restart required.

### 2.3 If something fails

| Toast / error | Cause | Fix |
|---|---|---|
| "no intrinsics loaded" | First-time setup — factory cal hasn't been read yet | SSH to the Pi: `python3 ~/<repo>/stewart_vision/scripts/calibrate_oak.py --stage factory`. Reads OAK EEPROM, writes `oak_intrinsics.yaml` in < 2 s. |
| "only N/8 markers visible" | Ring partially out of frame, glare, or lighting | Improve lighting, rotate camera arm, or rotate the platform manually so all 8 markers are in view. |
| "reproj exceeds 2 px gate" | Platform isn't actually leveled, or marker_layout.yaml doesn't match the printed ring | Re-level (Level ON; check IMU). Verify the ring radius matches `marker_layout.yaml` (`ring_radius_mm: 120.0`). |
| "estimatePoseBoard returned 0" | Detection geometry is degenerate (rare) | Reset, capture a different angle. |

### 2.4 Advanced (CLI on the Pi only)

Stages A and B (custom intrinsics + stereo recalibration) override
the OAK's factory tuning and are **deliberately not in the GUI** —
a misclick could replace a working factory cal with a half-baked
custom one.

If you genuinely need them:

```bash
ssh sorak@stablebot.local
cd ~/<your-workspace>/src/stewart_vision/scripts
python3 calibrate_oak.py --stage A    # ~30 chessboard captures
python3 calibrate_oak.py --stage B    # stereo extrinsics
```

These are rare maintenance operations. The factory calibration is
within OAK's published spec (≤ 0.3 px reprojection); your custom
one might be slightly tighter, but the demo is not bottlenecked by
this.

---

## 3. The Vision Debug panel

Top of the left column. Collapsible — collapse it during demos to
keep the screen clean; expand it whenever something looks wrong.

### 3.1 Live camera feed

- 15 fps JPEG-compressed RGB stream.
- Frames drop silently when the hotspot link is congested. The
  control loop is unaffected — it runs at full rate on the Pi
  regardless of what the laptop sees.
- **FPS** indicator shows the actual delivered rate. If it drops
  below ~5 fps, the laptop link is your bottleneck — close any
  bandwidth-heavy apps.

Toggles:

| Toggle | Effect |
|---|---|
| Show stereo | Replaces the RGB feed with side-by-side rectified left + right pair. Useful for verifying rectification (epipolar lines should be horizontal). |
| Show disparity | Replaces the feed with the OAK's color-mapped SGBM disparity map. Useful for verifying depth coverage of the platform. |

### 3.2 Telemetry strip

| Indicator | What it means | Healthy range |
|---|---|---|
| ArUco markers visible | Markers detected by `platform_pose_node` (n / 8) | 6+ during demos; 8 / 8 ideal |
| KF NIS | Normalized Innovation Squared from `ball_kf_node` | 0.5 – 5 most of the time |
| End-to-end latency | OAK exposure → `/ball_state` on the laptop | < 40 ms |
| OAK-vs-mono | mm error between OAK truth and classical mono ray-plane | green < 5 mm |
| OAK-vs-stereo | mm error between OAK truth and classical stereo triangulation | green < 5 mm |
| mono-vs-stereo | mm disagreement between the two classical methods | green < 5 mm |

Color coding for the three method-comparison KPIs:

- **green** — |error| < 5 mm — methods agree.
- **yellow** — 5 mm ≤ |error| < 15 mm — minor disagreement; keep
  watching but no action needed.
- **red** — |error| ≥ 15 mm — significant disagreement; one
  method has an issue. The CONTROL loop is unaffected (it only
  uses OAK truth) but you should investigate after the run.

---

## 4. Demo 1 — Orbit at fixed radius

The ball orbits the platform center at a user-set radius and
period.

### 4.1 Pre-flight

- [ ] Calibration is fresh (Stage C done since last camera move).
- [ ] Platform is armed and Level ON.
- [ ] Vision Debug shows ≥ 6 ArUco markers visible.
- [ ] Foam ball placed on the platform anywhere outside the red
  dead-zone disk.

### 4.2 Run the demo

1. Open the **Demo 1 — Orbit** panel (middle column).
2. Set:
   - **Radius** (35 to ~195 mm)
   - **Period** (1 to 10 s — one full orbit)
   - **Direction** (CW / CCW)
3. Click **Start**. The platform first drives the ball *to* the
   orbit radius (acquisition phase, ~2-4 s), then engages the
   orbit reference. The mini-SVG disk shows the reference circle
   and the measured ball trail.
4. Mid-orbit you can press the **UNO-reverse** button (yellow,
   two curved arrows) to flip direction. The ball decelerates
   through zero and accelerates the other way — a good visual
   stress test of the controller.
5. Click **Stop** when done. The platform drops to LEVEL_HOLD.

### 4.3 What to expect

- Tracking error should be ≤ 5 mm RMS once warmed up.
- Latency in the Vision Debug strip should stay < 40 ms.
- If the ball wanders, check latency and KF NIS first.

---

## 5. Demo 2 — Click-to-Goto

The ball stays put until you click somewhere on the SVG disk; then
the controller drives the ball to that point and holds.

### 5.1 Pre-flight

Same as Demo 1.

### 5.2 Run the demo

1. Open the **Demo 2 — Click-to-Goto** panel.
2. Click **Start** to arm goto mode.
3. Click anywhere on the SVG disk that's:
   - Inside the platform circle (200 mm radius).
   - Outside the red dead-zone (~30 mm-radius disk at center).
4. The ball drives to that point and holds. Current target is a
   hollow blue ring; ball is the filled blue dot.
5. Click another spot — the ball cancels and re-targets
   immediately. No queueing.
6. **Cancel target** clears the reference (ball stays put,
   LEVEL_HOLD).
7. **Stop** disarms Demo 2 mode.

### 5.3 Toggles

| Control | Effect |
|---|---|
| **Predicted path** (default off) | Dashed line from current ball position to target. Useful for debugging the PID's approach trajectory. |
| **Z-height slider** | Pure heave on the top plate (no tilt). 0 to 80 mm above neutral. Adjustable while a goto is in progress. |

### 5.4 Failure handling

If the ball is bumped off the platform mid-demo, the off-platform
watchdog fires (see §7).

---

## 6. Demo 3 — Path drawing (stretch goal)

You draw a freehand path on the SVG disk; the ball follows it.

### 6.1 Drawing a path

1. Open the **Demo 3 — Path drawing** panel.
2. Click **Draw mode** to enable freehand drawing on the SVG.
3. Click and drag across the disk to trace a path. Sampling rate
   is ~30 ms per point.
4. As you draw, valid segments render in **green**; segments that
   cross the dead-zone or go off-platform render in **red**.
5. Release the mouse to finish. If any red segments exist, **Start**
   stays disabled — re-draw to clean up.

### 6.2 Running the path

1. Set:
   - **Loop** — checkbox; closes the path with a smooth join and
     repeats indefinitely until Stop.
   - **Traversal speed** — slider, default 80 mm/s.
2. Click **Start**. The ball drives to the path's start (using
   Demo 2's goto law), then traverses the path at the set speed.
3. **UNO-reverse** mid-traversal flips the direction at the ball's
   current path position. Trail-erase state resets on reverse.
4. **Stop** drops to LEVEL_HOLD. The drawn path is preserved —
   pressing Start again resumes from the start.

### 6.3 Display modes

| Mode | Effect |
|---|---|
| Trail-erase (default) | Segment behind the ball greys out as the ball passes. Best "you are here" cue. |
| Static green | Whole polyline stays bright green throughout. Toggle in the panel. |
| Predicted direction | Faint arrows along the polyline indicate traversal direction. |

### 6.4 Save / load / export

- **Save** to a named slot in browser localStorage. Survives
  page reloads and browser restarts.
- **Load** picks a saved slot; the path appears on the disk
  ready to Start.
- **Export** downloads the current path as `.json` (schema_version 1).
  Check it into git, share via email, etc.
- **Import** uploads a `.json` and loads it as the current path.

---

## 7. Safety system

### 7.1 Dead-zone (the red disk at the center)

Represents the ball's no-go zone. The IMU bolt protrudes through
the platform's geometric center; the ball must never touch it.
The disk's radius is 30 mm (10 mm clearance + 20 mm ball radius).

- Demo 2 clicks inside the dead-zone flash and are ignored.
- Demo 3 paths that cross the dead-zone are rejected with a re-draw
  prompt.
- Demo 1 orbit radius is silently clamped to ≥ 35 mm.
- **Soft repulsion** in the controller adds an outward tilt term
  if the *measured* ball strays into the dead-zone + margin —
  this kicks in BEFORE the ball can touch the bolt, even if the
  reference is somehow trying to drive it inward.

### 7.2 Off-platform watchdog

If the measured ball position has radius > 200 mm from center
(off the platform) OR both detectors lose it for > 500 ms:

1. Platform drops to LEVEL_HOLD immediately (silent).
2. GUI body background strobes red ~3 Hz for 3 seconds.
3. Background settles to a dim red tint until you re-arm.
4. A toast appears: "Ball lost — platform leveling. Replace ball
   on platform and press Start to re-arm."

To re-arm:

1. Place the ball back on the platform within the 180 mm
   hysteresis radius.
2. Wait ~1 second for the detection to confirm (the strobe
   dims).
3. Press **Start** in whichever demo panel was active.

Re-arm is **manual** by design — automatic resume while your hand
is still on the platform would be surprising.

### 7.3 Emergency stop

The big red **E-STOP** button at the top of the GUI calls
`/e_stop`. All six leg drives go to IDLE immediately. Use this if
anything looks wrong — runaway motion, smoke, unexpected geometry,
etc.

E-STOP requires manual recovery: arm again from scratch.

---

## 8. Shutdown

Always shut the Pi down cleanly before pulling power, or you'll
corrupt the SD card.

```bash
ssh sorak@stablebot.local
sudo shutdown -h now
```

Wait for the Pi's green activity LED to stop blinking (~10 s),
then unplug power.

---

## 9. Troubleshooting

| Symptom | Likely cause | Fix |
|---|---|---|
| Page loads but "no /status received" | Stack didn't fully start | Click Diagnostics → Hard reset stack. Wait 30 s. |
| Connection dot stays red after Connect | WS URL wrong, mDNS blocked, or rosbridge down | Use IP-based URL; if still red, SSH and `systemctl status stable_bot_gui`. |
| OAK not detected on the Pi | USB cable / port issue | SSH and `lsusb` should show `03e7:f63b` (Movidius MyriadX). Reseat cable into the blue USB-A 3.0 port. |
| ArUco markers detected but Stage C won't solve | Platform not actually leveled OR marker_layout.yaml mismatch | Re-level (Level ON; IMU within 0.1°). Verify `marker_layout.yaml` ring radius matches your printed ring. |
| Demo 1 orbit oscillates / wobbles | Hotspot link congested or PID tuning | Check Vision Debug latency. If > 50 ms, drop period to 5 s. If link is fine, may need to retune PID gains. |
| GUI clicks don't respond | Connection state stale | Click Connect to force reconnect. |
| Strobing red won't clear | Re-arm condition not met | Place ball within 180 mm radius, wait 1 s, press Start. |
| FPS readout shows 0 / very low | Hotspot bandwidth | Restart hotspot. Or, if just debugging on a desk near the Pi, switch the laptop to Pi's WiFi if available. |
| Method-comparison KPIs all red | Bad calibration extrinsics | Re-run Stage C calibration. |
| KF NIS consistently > 10 | Q or R noise mismatched | Check Vision Debug latency — high latency often masquerades as bad noise tuning. If latency is fine, the ball state KF needs Q/R retuning (advanced; see spec §8). |

---

## 10. Cheat sheet (one-page reference)

```
Cold start:
    Hotspot on → Pi power → wait 45 s → http://stablebot.local:8080/
    Connect → Arm → Go to rest → Level ON

Calibration (only after camera arm moves):
    Vision Debug → Calibration sub-panel
    8/8 markers visible → Capture frame → Solve

Demo 1 (Orbit):
    Set radius / period / direction → Start
    UNO-reverse mid-orbit if you want to flip
    Stop

Demo 2 (Click-to-Goto):
    Start → click any safe point → ball goes there → click again to retarget
    Stop / Cancel target

Demo 3 (Path):
    Draw mode → trace a path → Loop? → set speed → Start → Stop

If ball falls off → page strobes red → put ball back → Start to re-arm
Anything looks wrong → E-STOP → diagnose → re-arm from scratch
```

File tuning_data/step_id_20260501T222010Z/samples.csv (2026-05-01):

phase | trial_idx | start_marker | target_marker | target_x_mm | target_y_mm | ball_start_x_mm | ball_start_y_mm | settled | settled_at_s | t_in_trial_s | x_mm | y_mm | vx_mm_s | vy_mm_s | speed_mm_s | err_mm | v_toward_target_mm_s | imu_pitch_deg | imu_roll_deg | cmd_pitch_deg | cmd_roll_deg | phase_code
open_loop_rep0 | 0 | 1 | -1 |  |  | -114.03374910260045 | -43.1855851642822 |  |  | 2.0930001483066007e-06 | -114.03374910260045 | -43.1855851642822 | 0.0 | 0.0 | 0.0 |  |  | 0.2689685821533203 | 0.15452678501605988 | -3.0 | 0.0
open_loop_rep0 | 0 | 1 | -1 |  |  | -114.03374910260045 | -43.1855851642822 |  |  | 0.010118960999534465 | -114.03374910260045 | -43.1855851642822 | 32.59429707482195 | 10.448710106586077 | 34.22811336742387 |  |  | 0.2689685821533203 | 0.15452678501605988 | -3.0 | 0.0
open_loop_rep0 | 0 | 1 | -1 |  |  | -114.03374910260045 | -43.1855851642822 |  |  | 0.02490473500074586 | -112.84747506689966 | -42.805302887368725 | 62.24281687505891 | 19.892709827899466 | 65.34438121858012 |  |  | 0.26649269461631775 | 0.14619168639183044 | -3.0 | 0.0
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

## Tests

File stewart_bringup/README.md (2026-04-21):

# Stable-Bot Stewart Platform

Browser-controlled 6-DOF Stewart platform with dual-IMU closed-loop
leveling, keyframe routine playback, and data logging. Built on ROS 2
Kilted, six ODrive Pro motor controllers over CAN, and two Xsens MTi-630
IMUs (base + platform).

**Live pilot UI**: `http://localhost:8080/` once the stack is up.

---

## What's in this package

- `stewart_bringup/stewart_control_node.py` — the one long-lived ROS 2
  node. Owns the CAN bus via a per-leg-mode `ODriveFeeder` (50 Hz
  `Set_Input_Pos` with velocity feed-forward), passive + RTR
  `EncoderListener` for encoders / errors / Iq, PI level loop, homing
  subprocess orchestrator, routine playback + data logging. All GUI
  actions reach it via a `/control_cmd` topic dispatcher (see
  [`ARCHITECTURE.md`](docs/ARCHITECTURE.md)).
- `web/index.html` — single-file web GUI, roslibjs + Tailwind via CDN.
- `launch/stewart_gui_launch.py` — bundled launch: dual Xsens IMUs +
  control node + rosbridge on `ws://localhost:9090`.
- `scripts/gui_server.py` — tiny HTTP server that serves the HTML **and**
  exposes `/reset`, `/launch`, `/stop_launch`, `/launch_status`
  endpoints so the browser can recover the backend when rosbridge is
  unreachable.
- `scripts/reset_stewart_stack.py` — one-shot recovery: kills stale
  processes, frees port 9090, restarts the ros2 daemon, optionally
  relaunches + polls `/status` to verify the stack is actually
  publishing.
- `scripts/analyze_routine_log.py` — offline analyzer for recorded
  routines; plots commanded vs measured tilt, leg currents, and runs a
  rolling-sphere ball-on-disk simulation against the measured IMU data.
- `scripts/read_odrive_errors.py` — RTR query of every ODrive's
  `active_errors` + `disarm_reason` with human-readable decode.

---

## Hardware inventory

| Item | Interface | Role |
|---|---|---|
| 6 × ODrive Pro (firmware 0.6.x) | CAN (gs_usb adapter) | leg motor drives |
| 2 × Xsens MTi-630 | USB-serial at 921600 baud | base + platform IMUs |
| 6 × 3D-printed linear actuators (~71 mm / motor rev) | — | legs |
| Stewart top plate (carbon fiber, ~400 mm Ø) | — | platform surface |

---

## Quick start (WSL2 laptop, one double-click)

If USB-CAN and both IMUs are already `usbipd attach`-ed, the fastest
path from desktop to running GUI is the Windows launcher:

**Double-click `scripts/start_stable_bot.bat`** — brings up can0, starts
`gui_server.py` on :8080, runs `ros2 launch`, opens the browser. Two
WSL windows stay open so you can watch logs; close them to shut down.

Companion launchers in the same folder:
- `scripts/stop_stable_bot.bat` — clean teardown (kills every Stable-Bot
  process)
- `scripts/reset_stable_bot.bat` — one-click hard reset + relaunch +
  verify (wraps `reset_stewart_stack.py --launch --verify`)

### Manual start (three terminals)

If you prefer terminals or need finer control, three WSL panes sourced
to ROS 2 Kilted + workspace overlay:

```bash
source /opt/ros/kilted/setup.bash
source ~/ros2_ws/install/local_setup.bash
```

**Terminal 1** — CAN bus up (needs sudo once per session):
```bash
sudo ip link set can0 up type can bitrate 1000000
sudo ip link set can0 txqueuelen 1000
```

**Terminal 2** — HTTP server serving the GUI + recovery endpoints:
```bash
python3 ~/ros2_ws/src/stewart_bringup/scripts/gui_server.py
```

**Terminal 3** — The ROS 2 stack:
```bash
ros2 launch stewart_bringup stewart_gui_launch.py
```

Open `http://localhost:8080/` in a browser.

---

## Quick start (Pi — headless, auto-boot)

See [`docs/PI_MIGRATION.md`](docs/PI_MIGRATION.md) — includes headless
WiFi setup (phone hotspot), ROS 2 install, systemd services, and how to
control the robot from your laptop browser over WiFi.

---

## Typical session flow

1. Open GUI. Wait for the Status panel to populate (≤ 2 s).
2. Click **Read now** in the ODrive errors panel. All 6 should read `OK`.
   If any don't, click **Clear all**; if they re-latch, power-cycle.
3. Run the homing section's **Stall-home this leg (bottom)** once per
   leg (or all 6 selected together). Respond `y` in the stdin box when
   prompted.
4. If you need a leveled reference, use the **Stabilization** card:
   Arm → Level ON → drag Z slider to desired height → watch the
   roll/pitch errors settle to green (<0.1°).
5. For rolling-ball or routine demos: record a routine with the **rec**
   checkbox, then analyze it offline with
   `analyze_routine_log.py --all`.

---

## One-command recovery

When anything goes wrong (GUI stuck on "waiting", ODrives red-pulsing,
CAN bus-off, etc.):

```bash
python3 ~/ros2_ws/src/stewart_bringup/scripts/reset_stewart_stack.py --launch --verify
```

This kills everything, frees port 9090, restarts the ROS daemon,
relaunches the bundle, and polls `/status` to confirm it actually came
up. Full diagnostics in the terminal; full log saved to
`logs/last_launch.log`.

For deeper trouble, see [`docs/TROUBLESHOOTING.md`](docs/TROUBLESHOOTING.md).

---

## Data output

Recorded routine runs land in `~/ros2_ws/src/stewart_bringup/logs/<timestamp>_<routine>/`:

- `routine.json` — exact copy of the routine played
- `metadata.json` — motor limits, level cal, PI gains, feature flags
- `telemetry.csv` — 50 Hz: commanded pose, IMU RPY/accel/gyro, encoder
  positions, Iq, level corrections, per-leg modes
- `can.log` — raw `candump -L` capture
- `end.json` — final duration + timestamp

Bulk-compare all logs:
```bash
python3 ~/ros2_ws/src/stewart_bringup/scripts/analyze_routine_log.py --all
```
Writes `logs/summary.csv` with one row per run + ball-trajectory metrics.

---

## Further reading

- [`docs/ARCHITECTURE.md`](docs/ARCHITECTURE.md) — process graph, topic flow, control algorithms
- [`docs/PI_MIGRATION.md`](docs/PI_MIGRATION.md) — Phase 8: move backend to a Raspberry Pi
- [`docs/TROUBLESHOOTING.md`](docs/TROUBLESHOOTING.md) — consolidated fixes for all the issues seen during bring-up

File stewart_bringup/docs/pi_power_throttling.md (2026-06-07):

# Pi 5 power throttling — investigation + fixes

**Added 2026-06-05.** During the latency-instrumentation work the demo/bench
digests showed the Pi **pegged at ~100% CPU, load ~26 (4 cores!), and
`throttled_now=True`** at only ~58 °C. That contaminates every latency and
bench number (the detect→state split swings, the bench gain reads garbage
from a starved excitation thread). This doc records what's going on, how to
diagnose it, and what to do — so we don't re-derive it.

The host stats are now captured automatically: gui_server's `/system/stats`
(GUI banner, red = throttling) and `<bag>/system_stats.jsonl` →
`digest.summary.json.host`.

## ✅ RESOLVED (2026-06-07): it was the BEC back-feeding the Pi rail

The acute under-voltage was **not** (only) a weak Pi PSU — it was the **Castle
BEC paralleled onto the Pi's 5 V rail (via the powered USB hub) fighting the
USB‑C PSU**. Two unmanaged 5 V sources on one rail: the slightly-lower BEC
**sank / back-fed current instead of contributing**, dragging the rail to
`EXT5V_V = 4.88 V` even at idle, so transient load spikes sagged past the
~4.6–4.8 V threshold → throttle. (This corrects the note below that the
"OAK-on-the-BEC separate rail… helps" — it was *tied to the Pi 5 V through the
hub*, not separate.)

**Unplug the BEC from the Pi rail →** `EXT5V_V = 5.03 V`, `get_throttled = 0x0`,
2.4 GHz steady, **zero throttling**, at 55–58 °C. The operator's USB‑C supply
straight into the Pi's port is adequate **on its own**; the BEC was the problem.

**Rule:** never parallel two unmanaged 5 V sources on the Pi rail. Power the Pi
from ONE path (or proper ideal-diode OR-ing).

### CAN common ground (the catch after removing the BEC) — confirmed 2026-06-07
The BEC's 5 V **return** was also the Pi↔ODrive **CAN common ground**. Remove the
BEC's 5 V and CAN dies (Pi sees no ODrives in the GUI) because the transceivers
have no shared reference. Fix: run a **GROUND-ONLY** wire from any 48 V-system
ground point (an ODrive GND terminal / the CAN connector GND pin / the BEC's
black/0 V) to the Pi's ground. This is safe and does NOT back-feed — back-feed is
a 5 V-*source* conflict; a 0 V reference tie carries only the mA-level CAN signal
return, and the Pi still draws its power from its own USB‑C brick. **Connect the
GND wire only; leave the 5 V disconnected.** Best practice: run GND alongside
CANH/CANL in the harness so the reference travels with the bus. Verify CAN is
clean (ODrives enumerate, no rising error counts) **before arming**.

### Keep the clock pinned (operator wants max perf, doesn't care about idle draw)
```bash
echo performance | sudo tee /sys/devices/system/cpu/cpu*/cpufreq/scaling_governor
```
Persist with `scripts/cpu_performance.service` (a oneshot that sets it on boot).
Holds the stock 2.4 GHz so a load spike doesn't pay the DVFS ramp-up latency —
*not* an overclock. Watch `temp` stays < 80 °C under long demos.

## TL;DR

1. **It's under-voltage, not heat** (58 °C is cool; thermal limit is ~80–85 °C).
   The SoC firmware itself raised the flag because the 5 V rail sagged under
   load.
2. **The Pi 5 needs a 5 V/5 A (25 W) USB-PD supply.** High-wattage GaN
   chargers do NOT count — they deliver their big wattage at 20 V/28 V, and
   only **5 V/3 A (15 W)** at 5 V. A Pi 5 under full load wants up to ~5 A at
   5 V, so 15 W brown-outs → throttle.
3. **Order: the official Raspberry Pi 5 27 W PSU** (5.1 V/5 A). Likely the
   single fix. An **Active Cooler** is cheap insurance once it holds full
   clock. An **NVMe SSD + HAT** only if the bag recorder turns out I/O-bound.
4. **2.4 GHz is the Pi 5 stock max.** Idle it scales down to ~1.5 GHz (normal
   power saving, NOT throttling) — so always read `measure_clock arm` *under
   load*.

## Why our chargers fail (the counterintuitive part)

The Pi takes a fixed **5 V** input. What matters is amps **at 5 V**, not the
sticker wattage.

| Supply / port | Amps at 5 V | Verdict for Pi 5 |
|---|---|---|
| Official Pi 5 PSU | **5 A (25 W)** | ✅ what it's designed for |
| Anker 33 W | 3 A (15 W) | ❌ marginal → brown-out under load |
| Anker 140 W **A2697**, port C1/C2 | 3 A (15 W) — 5 A only at 20/28 V | ❌ |
| Anker 140 W **A2697**, port **C3** (used) | 3 A (15 W), 40 W port | ❌ |

So "140 W" is irrelevant here — every port on the A2697 caps at **5 V/3 A**.
The 5 A profiles are at 20 V/28 V, which the Pi can't use. (Per-port specs:
Anker A2697 user guide.) Long/thin cables make it worse via IR drop; the
official PSU has a short captive cable for exactly this reason.

The OAK being on a separate rail (Castle BEC Pro → hub) is correct and helps
— it keeps the OAK's ~1.2 A off the Pi's 5 V — but it does nothing about what
the **Pi's own** brick can deliver.

## The cascade that produces "load 26"

Under-voltage doesn't just slow one thing — it snowballs:

```
inadequate 5 V rail  →  firmware caps the ARM clock (throttle)
   →  the normal ROS2 + cv2 workload no longer fits the reduced CPU
   →  CPU pins at 100%, runnable threads pile up  →  load average climbs to ~26
```

So load 26 is a *symptom*. Fixing the rail (full 2.4 GHz restored) should
drop it a lot on its own. If it DOESN'T, the remaining load is genuine
compute (see below).

## Diagnosis toolkit (run on the Pi)

Power / clock (no sudo needed for vcgencmd):
```bash
vcgencmd get_throttled        # 0x0 = healthy; bit 0x1 = under-volt NOW; 0x10000 = since boot; 0x4 = throttled NOW
vcgencmd measure_clock arm    # UNDER LOAD: should hit ~2.4e9; if it sags, throttling
vcgencmd measure_volts core   # the actual core voltage
sudo dmesg | grep -i volt     # firmware logs "Undervoltage detected!" (needs sudo — dmesg_restrict)
```

What's eating CPU / IO (CPU-bound vs IO-bound):
```bash
htop                 # press P = sort by CPU; the node processes (python3 stewart_control_node, oak driver, rosbridge…)
top -H               # per-THREAD (find a single pegged thread inside a node)
iotop -ao            # accumulated disk I/O per process — confirms if `ros2 bag record` is the writer
iostat -x 1          # %util near 100% on the SD card = disk saturated
uptime               # load average — compare idle vs during a recording run
```
Rule of thumb: **high load + high %CPU = compute-bound**; **high load + high
%wa (iowait) + modest %CPU = I/O-bound** (the SD card / bag writer). Our runs
showed ~100% CPU → primarily compute (made worse by the throttle).

## Fixes, in order

1. **Official Pi 5 27 W PSU (5.1 V/5 A)** — ~$12. The actual fix for the
   under-voltage. Keep the OAK on the BEC.
2. **Pi 5 Active Cooler** — ~$5. Once the clock holds 2.4 GHz under sustained
   load the SoC runs hotter; active cooling keeps it off the thermal limit
   and lets `arm_boost` stay on. Cheap insurance.
3. **Cut compute** (if CPU is still pegged WITH a good PSU):
   - **Minimal-topic recording** for latency runs — drop the 400 Hz pixel/
     diagnostic streams; bag only `/ball_state`, `/ball_xy_mono/lat`,
     `/platform/imu/data`, `/latency_bench/diag`, `/status`. (We can add this
     toggle to the recorder.)
   - **mcap `fastwrite` preset** for `ros2 bag record` — disables CRC +
     indexing for lowest resource use on constrained machines.
   - Lower `OAK_JPEG_FPS` / RGB fps if the host cv2 path is hot.
4. **NVMe SSD + Pi 5 M.2 HAT** — ~$30–50. Only if `iotop`/`iostat` show the
   recorder is I/O-bound on the SD card. Massive win for high-rate logging if
   so, but verify first.

## Notes specific to this rig
- `usb_max_current_enable=1` is set in `config.txt` (for the OAK's USB draw on
  the old single-supply setup). With the OAK now external this is harmless,
  but it means the Pi won't *self-limit* on a weak PSU — it'll draw until the
  rail sags, which is exactly the under-voltage we see.
- Don't bother **overclocking** past 2.4 GHz while fighting under-voltage —
  it raises voltage/heat/draw, the opposite of what we need. The goal is to
  reliably *reach* 2.4 GHz under load, not exceed it.

## Profiling the compute (the Pi held 2.4 GHz → compute-bound, not throttled)

Find the hog in increasing resolution:
1. `htop` (press **P** = sort by CPU). Expect: OAK driver (cv2), rosbridge,
   `ros2 bag record`, control node.
2. **py-spy** on the Python nodes — attaches live, no restart:
   ```bash
   sudo py-spy top  --pid $(pgrep -f oak_driver_node)        # live which-function
   sudo py-spy dump --pid $(pgrep -f stewart_control_node)   # call stack / thread
   sudo py-spy record -o oak.svg --pid <pid> --duration 20   # flame graph
   ```
   Pinpoints e.g. `getCvFrame` vs HSV vs projection vs publish.
3. `sudo perf top` — system-wide incl. C (Fast-DDS, cv2 internals, rosbridge).
4. The digest `host` block now tags **compute-bound** vs **I/O-BOUND (disk)**
   via the iowait split — read that first.

## Increase throughput WITHOUT adding latency

Latency = the see→move *critical path* (capture→detect→localize→KF→control→
actuate). Much of "load 26" is NOT on that path — it steals CPU from it:
rosbridge serialising to the browser, `ros2 bag record` serialising 400 Hz
IMU, the GUI live feed. **Cutting that bookkeeping frees the critical path →
lower latency** (live-video off, fewer/throttled browser subs, minimal-topic
recording, mcap `fastwrite`).

The bigger lever: **offload vision to the OAK's own VPU.** DepthAI "does the
heavy lifting… leaving the host CPU free for business logic"; the host
`getCvFrame()` copies the full ~1.5 MB frame each time. Detecting on-device
and shipping only (cx,cy) deletes that copy + the host HSV — the Pi then only
runs the light control. (Scoped in `oak_phase2b_on_device_v0.md`; caveat: the
on-device detector must match the host cv2's motion robustness — the earlier
YOLO attempt didn't, so this needs detector work, not just a flag.)

## Should we switch off the Pi 5? — profile + offload first

Load 26 at *full clock* for a control + camera task is a software-utilisation
smell, not a hardware ceiling; a clean version runs at load 2–4. The OAK
already has a VPU, so **we don't need a host GPU for the vision.**

If it still can't keep up after offloading:

| Option | vs Pi 5 | Why / why not | Effort |
|---|---|---|---|
| **Intel N100 mini-PC** (~$150) | ~3× CPU | x86, ROS 2 **binary** install (no 3 h source build), big headroom. No GPIO → CAN via USB adapter (SocketCAN). Best $/CPU. | port workspace + USB-CAN + re-test (~days) |
| **Jetson Orin Nano** (~$249) | ≈CPU, +CUDA/TensorRT (100+ FPS YOLO vs 5–15 on Pi) | GPU is **redundant here** (the OAK does vision); only worth it for heavy *on-host* NNs later. 25 W. | JetPack/Isaac + port (~days+) |
| **Stay on Pi 5** | — | Likely fine after offload + cutting bookkeeping; CAN HAT already wired. | software only |

**Verdict: don't switch yet.** Profile → offload vision to the OAK → cut the
browser/recorder load → re-measure. A switch is a multi-day port (ROS 2 +
depthai + CAN + re-test) and probably unnecessary.

## Sources
- Raspberry Pi 5 PSU / under-voltage: pimylifeup, peppe8o, RPi forums
  (t=381080 "5V/5A power issues", t=371450, t=382143).
- Clock / throttle monitoring: Jeff Geerling (overclocking the Pi 5),
  jamesachambers (measure undervoltage + true clock), Tom's Hardware
  (vcgencmd benchmark).
- I/O-wait diagnosis: Netdata, Site24x7, Alibaba ECS (iostat+iotop).
- rosbag2 / mcap on constrained machines: ros2/rosbag2#1787, mcap.dev
  storage-plugin benchmarks (fastwrite preset).
- Profiling: benfred/py-spy (sampling profiler, attach by PID);
  awesomebytes/python_profiling_tutorial_with_ros.
- Compute offload: Luxonis DepthAI docs ("device does the heavy lifting"),
  LearnOpenCV intro to OAK-D/DepthAI.
- Hardware: Pi 5 vs Jetson Orin Nano (kunalganglani, ThinkRobotics,
  hackster); Pi 5 vs Intel N100 (CNX Software, Jeff Geerling, Tom's Hardware).

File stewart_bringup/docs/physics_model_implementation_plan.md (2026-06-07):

# Physics-model control — implementation plan & interaction map

**Companion to `ball_physics_modeling_plan.md`** (which has the physics, the
data campaigns §5, the §15 GUI sketch, and the §13 logging). *That* doc says
*what physics to capture*; *this* doc says *exactly what code changes wire it
into the live control schema*, phase by phase, with every interaction point
so we can flip PID ⇄ model and know which ran in every bag.

Driven by the 2026-06 latency work (`latency_headroom_journey.md`): the loop
is ~264 ms, decoupled from CPU, and the controller already predicts the ball
`Td` ahead — so the model is a *better predictor*, not a latency fix.

## Decisions resolved (operator + recommendation, 2026-06-06)

- **Z dependence → one model, validate across Z; don't pre-build per-Z.**
  The ball *rolling* dynamics (`a = (5/7)g·sinθ`, friction ∝ `mg·cosθ`) are
  Z-independent at steady Z — Z is the heave, not the tilt. The Jacobian's
  Z-dependence is on the *actuation* side (leg-motion→tilt), which the model
  doesn't touch (it predicts ball-given-*measured*-tilt). So fit one model at
  the demo Z, then run a held-out check across Z; only add a Z term if the
  horizon error grows at the extremes.
- **Platform regions (center/middle/edge) → one model, but DO collect
  coverage across regions.** For a rigid, uniform plate the physics is
  position-independent. You don't need a model *per* region — but you *do*
  want data spanning regions so the fit (a) is validated everywhere and (b)
  surfaces any surface-friction inhomogeneity as a region-dependent residual.
  If that residual shows up, add a position-dependent friction term (or a GP
  residual) — let the data decide. The coverage-grid campaign (§5G) drives
  this for free.
- **Excitation → chirp above the stiction breakaway + the dedicated
  breakaway campaign (§5B).** Our system is stiction-dominated (needs the
  startup ramp to break loose), so a small-amplitude chirp won't move the
  ball. Use chirps at amplitudes that actually roll it for the rolling/
  frequency content, and campaign B for the static/rate/dwell breakaway that
  the LuGre (Tier-3) friction term needs. PRBS only if the spectra need it.
- **IMU → platform IMU is primary; log both (free).** The platform IMU gives
  tilt + ω + plate accel (the Tier-2 coupling terms). A base IMU only matters
  if the *rig* moves; for a fixed base it's redundant. `imu_dual` already
  records both, so keep logging both and use the base one only if a coupling
  residual demands it.
- **Tune KF `R` first → yes, cheap, do it in Phase 0/1.** Damping vision
  spikes at the source may matter more than model form (plan §10/§19). It's a
  `ball_kf_node` measurement-noise parameter; raising `R` (or gating outlier
  jumps) trades responsiveness for smoothness. Low-risk A/B.

## Phase 0 — control-method switch — SHIPPED ✅

The infrastructure to flip PID ⇄ model, behind a flag, default-off and
**provably behaviour-neutral** until a model exists. Deploy is zero-risk.

**Interaction map (what touches what):**

| piece | file:symbol | role |
|---|---|---|
| predictor | `_ball_predictor.py:predict_lead()` | pure lead-position fn; `const_vel` = `x+v·Td` (exact), `model` = `model.integrate(...)` with a const-vel fallback (a model bug can't command a wild tilt). |
| model loader | `_ball_predictor.py:load_ball_model()` | returns None today → const-velocity everywhere. Phase 1 returns a fitted model. |
| the flag | `ball_track_gains['use_model_predictor']` (default 0) | rides the gains dict → `/status` → digest. |
| read site | `stewart_control_node._predict_lead()` | picks method from the flag + `self._ball_model`. |
| swap site 1 (bang-bang) | `_ball_track_run` ~L4627 | `if use_model: px_lead,py_lead = _predict_lead(...) else: <legacy inline>` |
| swap site 2 (PID) | `_ball_track_run` ~L4707 | same branch; `ex_lead = ex + (px_lead-px)` (== legacy for a static ref) |
| set command | `/control_cmd` `set_control_method:{value: pid\|model}` | targeted single-flag set (doesn't touch other gains), mirrors `set_speed_cap`. |
| GUI | demos panel `#demo-control-method` dropdown | publishes `set_control_method`. |
| label | `digest_demo_bag.summary.control_method` + stdout | `'model'` iff `gains_at_record.use_model_predictor`. **Zero new bag topics.** |
| artifact path | `config/ball_model.yaml` (`BALL_MODEL_PATH`) | absent today; Phase-1 fitter writes it. |
| tests | `test/test_ball_predictor.py` (6, pass) | pins const-vel exactness + stub neutrality + the broken-model fallback. |

**To use it now:** deploy + flip the demos "control method" dropdown to
*Physics model* — it currently does nothing (const-velocity fallback), which
is the point: it proves the plumbing (dropdown → `/status` → digest label)
before any model risk.

## Phase 1 — the modeling pipeline (the real build)

**Build (plan §9), in dependency order:**
1. `scripts/fit_ball_forward_model.py` — offline gray-box fitter (Tier-1→2→3,
   optional GP residual), writes `config/ball_model.yaml` + a fit report.
2. `_ball_physics.py` — Tier-2 coupling + Tier-3 LuGre/rolling-resistance.
3. The model class with `.integrate(px,py,vx,vy,td_s,tilt_history)` — drop it
   into `load_ball_model()`; `predict_lead`'s `'model'` branch already calls it.
4. **Control-node Phase-1 adds:** a commanded-tilt **ring buffer**
   (`self._tilt_history`, append each tick) so the model integrates through
   the known input; and **per-sample `Td`** (`Td = /oak/latency_ms + fixed
   actuation_offset` instead of the fixed `control_latency_s` — plan §19.1,
   kills the jitter term; gate behind its own flag for an A/B).
5. Excitation modes in the control node, driven by `/control_cmd`
   `data_collect:<campaign>:<json>` (§15).

**The "Physics Modeler" GUI panel — top of the right column** (3rd
`<section class="lg:col-span-1">`; auto-tune / step-id / latency-bench shift
down — auto-tune is already env-disabled so it's inert). Clone the STEP_ID
endpoints (`/data_collect/bags`, `/.../digest`, `/.../png`, `/.../push`):
- per-campaign **Run** buttons (meas-noise, breakaway, coasting, step-ID,
  sweep, coupling, coverage-grid),
- a **live coverage heatmap** (state-space bins → fill the next under-sampled
  cell, incl. the platform-region coverage above),
- a **run-QA strip** (axis_state / feeder_mode / errors / latency / det-rate;
  auto-abort + `_fault` tag — plan §14),
- a **session list** (digest/PNG/push) and a **model panel** (the §18
  sim-vs-real error viz so you watch the fit close on reality).

**Logging (plan §13, manifest v2)** — for the *data-collection* bags only
(the demo digest already has what it needs): expand the allowlist to the
dropped-but-needed topics (`/oak/latency_ms`, `/oak/health`,
`/ball_track/diagnostic`, `/level_diag`, `/leg_currents`, per-motor
`RobotState`, CAN traffic) + a per-bag metadata sidecar.

## Robust tests (the report card)

1. **Unit (pytest, pure):** Tier-1/2/3 integration vs analytic cases;
   `predict_lead` const-vel exactness + model-stub neutrality (done);
   the **fitter recovers known params** from synthetic data (inject θ_s/μ_s/
   G_eff → fit → assert recovery); §14 QA gates fire on synthetic bad runs.
2. **Validation:** input-replay **sim-vs-real**; the **horizon-error curve**
   (predicted-vs-actual at lookahead 0→264 ms on *held-out* bags) — this is
   the "is 264 ms inside the trustworthy horizon" answer; learning curve
   (error vs data quantity → §17 stopping criteria).
3. **A/B (the payoff):** PID vs model over the same click-to-goto set —
   tracking rms/p95/settling **and** horizon-error, side-by-side in
   `compare_demo_bags`, auto-labeled by `summary.control_method`. **Instant
   fallback = flip the dropdown to PID.**
4. **Safety / HIL:** the model path inherits PID's `max_tilt` clamp and the
   const-velocity fallback (a model exception can't escape it); audit the
   lost-ball → hold-level/disarm watchdog *before* trusting the model online.

## Sequencing / open items

- Phase 0 is shipped + safe to deploy now (validates the switch end-to-end).
- Phase 1 minimal core = campaigns **B/C/D + coverage grid** → a Tier-1/2
  predictor + the horizon-error curve. Resist building all 7 campaign
  buttons before the first model proves out. Sim/MPC (plan §8.3) waits.
- Phase-0 gaps to close in Phase 1: reflect the dropdown from `/status`
  (cosmetic); the tilt-history ring buffer; per-sample `Td`.
- The **`R`-tune** and **per-sample `Td`** are independent quick wins worth
  doing alongside, since the *jitter* (not the mean) drives the limit cycle.

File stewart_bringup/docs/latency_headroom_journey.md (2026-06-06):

# Latency + headroom journey — slaying the Pi-saturation dragon (2026-06)

**What this is.** A retrospective of the multi-day effort that took the
closed-loop see→move latency from **~450 ms to ~264 ms**, the Pi from
**100 % CPU / load 22** to **~96 % / load 8.7**, and — the real prize —
made the **latency decoupled from host load** (cpu↔latency correlation
+0.47 → −0.20). Written so we don't re-derive the findings, and so the
*next* person understands why the system is shaped the way it is.

## TL;DR — the numbers

| metric | start | end | what moved it |
|---|---|---|---|
| see→move loop latency | ~450 ms | **~264 ms** | almost entirely the 2 t/s actuation cut |
| actuation (cmd→motion) | ~285 ms | **105 ms** | leg speed cap 1.0 → 2.0 turns/s |
| OAK capture→Pi | 95 ms | **54 ms** | YOLO offload (no host cv2 frame-drain) |
| see-pipeline p50 (photon→state) | ~158 ms | ~159 ms | **unchanged** — inherent detect→state + staleness |
| load (1-min avg) | 22–26 | **8.7** | the whole waste-cutting campaign |
| cpu↔latency correlation | +0.47 (coupled) | **−0.20 (decoupled)** | freed headroom |
| tracking error rms | ~88 mm | 91 mm | unchanged (no capability lost) |

**Two structural wins did the heavy lifting; a pile of small "compute
nobody consumes" fixes freed the headroom that made them measurable.**

## The problem

Demo/bench digests showed the Pi 5 **pegged at 100 % CPU, load ~26 on 4
cores**, with the firmware `throttled` flag set at only 58 °C. Every
latency number was contaminated (the detect→state split swung run to run;
the bench gain read garbage from a starved excitation thread). We couldn't
tell if the platform was slow because of *power*, *compute*, or *the loop
itself*.

## Methodology — measure, don't guess

The single most important discipline: **profile before optimising.** Every
time we guessed the hot spot, we were wrong.

1. **Power vs compute first.** `vcgencmd get_throttled` / `measure_clock
   arm` separated under-voltage (the flag was the `0x1` under-volt bit, not
   thermal) from genuine compute. A proper 5 V/5 A PSU cleared the
   under-voltage; load 21 *remained* → compute-bound, confirmed.
2. **`scripts/profile_system.py`** (built for this): per-node %CPU/RAM/
   threads over a window + system aggregate + an automated **py-spy**
   own-time drill-down on the hottest Python nodes. This is what found
   every real hog. The bet was always wrong before py-spy: we predicted
   `getCvFrame`; the actual #1 was a discarded depth map.
3. **The cpu↔latency correlation digest** (`host_latency_correlation` in
   `_latency.py`): both timelines are co-recorded in every demo bag
   (`system_stats.jsonl` cpu/load @1 Hz + `/ball_state.orientation.z`
   per-frame photon→state age), so the Pearson r is the "did headroom help
   latency?" metric. Watching it flip +0.47 → −0.20 is how we *knew* the
   CPU was no longer the latency bottleneck.

## The recurring anti-pattern: compute nobody consumes

Most of the headroom came from finding work the Pi did every frame whose
result was thrown away:

| fix | what it was | reclaimed |
|---|---|---|
| `oak_driver` depth-map gate | `_expected_plane_depth_map` (540×960 meshgrid + per-pixel plane solve) rebuilt on every ArUco pose, but consumed **only** by the depth-blob detector — which is off by default (`OAK_ENABLE_DEPTH=0`). #1 hog, ~31 % of the busiest node. | ~0.3 core |
| `calibration_node` gate | full ArUco `detectMarkers` on **every** RGB frame forever — duplicating `platform_pose`'s identical detection — just in case the operator calibrates. Gated to an active session (GUI panel open). | ~0.35 core |
| `auto_tune_node` disabled | ~13 subs churning the executor for a node the operator no longer uses. `STABLE_BOT_AUTOTUNE=1` to restore. | ~0.23 core |
| legacy `bag_recorder_node` disabled | spawned its **own** `ros2 bag record` to `~/stable_bot_bags/` on every demo — fully redundant with the GUI auto-bag (→`tuning_data/`, the digested one). The "two `ros2 bag record`" mystery. `STABLE_BOT_LEGACY_BAGREC=1` to restore. | ~0.7 core |
| `_save_persisted_pose` throttle | wrote the commanded pose to the SD card **every control tick** (via `_do_set_pose`) for restart recovery. 1 Hz is plenty. | ~0.34 core |
| GUI live-video off by default + auto-drop on record | rosbridge serialising JPEG to the browser (`__repr__(CompressedImage)` was 22 % of the node) competes with the see→move path. | ~0.3 core when off |
| Vision Debug panel-collapse gating | the 4 per-frame detection-overlay streams unsubscribe when the panel is collapsed (they feed only `renderBallOverlays`). | rosbridge fan-out |

**Lesson:** on a *pegged* CPU, removing waste drops the **load** (run-queue
depth) but CPU stays ~100 % — the starved nodes immediately absorb the
freed cycles. So `load` (not `CPU %`) was the honest progress metric until
the very end. Watch the load trend: 22 → 17 → 14 → 11 → 8.7.

## The two structural wins

### 1. Vision offload to the OAK VPU (YOLO backend)
Switching the detector from host **cv2 HSV** to **on-device YOLO**
(`OAK_V0_BACKEND=v1_yolo`) deleted the host `detect_ball_v0` *and* the
60 Hz `rgb_raw` `getCvFrame` copy. Result: `oak_driver` −13 %, **capture→Pi
95 → 54 ms**, and tracking *held* (rms 76 vs cv2's 88 — YOLO sees the ball
fine). Its biggest contribution was **headroom + fresh-frame latency**, not
the see-*median* (which is staleness-dominated — see below).

### 2. Leg speed cap 1.0 → 2.0 turns/s — the actuation lever
This is what actually cut the *loop* latency. The control node commands the
ODrive `vel_limit = soft_cap × 1.5` at runtime, so doubling the soft cap let
the legs reach commanded tilt faster: **actuation 250–285 ms → 105 ms.**
That single change is ~all of the 450 → 264 ms loop reduction. Cost:
~2× peak leg current → re-confirm power before running at 2 t/s.

## Where the remaining latency lives

The **see-pipeline p50 (~159 ms) did not move** across the whole campaign —
it's dominated by **detect→state** (localizer + KF tick + the 27→12.6 Hz
inter-detection staleness, `ball_physics_modeling_plan.md` §20), not by
transport. So:
- The **actuation** half is now small (105 ms) and bounded by motor speed.
- The **see** half (159 ms) is the inherent pipeline — the next frontier if
  more latency is wanted, and it's *not* CPU-bound (the −0.20 correlation
  proves it).

## Is 264 ms "good"? — read this with §19 of the physics plan

Naively, 264 ms is high for 0.5 mm-class control of a fast ball. **But the
controller predicts the ball `Td` ahead (`x̂ = x + v·Td`)**, so latency is a
*prediction horizon*, not a raw penalty. The physics-modeling plan's whole
premise is a model-based predictor (Smith-predictor / known-input EKF that
forward-integrates the ball through the **known** ~283 Hz tilt over the dead
time). The plan's §19 verdict already said 108 ms is "only tolerable with a
model-based predictor" — at 264 ms that's more true, **and that predictor is
the planned work.** The 2 t/s win matters doubly here: it shortened the dead
time the predictor must cover by ~145 ms, making the model's job easier.

**The right next question is not "cut more latency" but "does the model
predict ~264 ms ahead within tolerance?"** — i.e. the plan's horizon-error
curve (§17), extended to 264 ms. Measure that before cutting further. Also
prefer feeding the **per-sample** `/oak/latency_ms` to the predictor over a
fixed `control_latency_s` (plan §19 mitigation #1) — the jitter, not the
mean, was the limit-cycle culprit.

## Tooling left behind

- **`scripts/profile_system.py`** — per-node CPU + py-spy drill-down, `--compare` deltas, `--push`. The workhorse.
- **`_latency.host_latency_correlation` + `read_system_stats_series`** — the cpu↔latency metric, surfaced in `digest_demo_bag.py` (`summary.host_latency_correlation` + a scatter panel). Re-runs on every demo digest.
- **Env gates** for re-enabling the disabled-by-default nodes: `STABLE_BOT_AUTOTUNE`, `STABLE_BOT_LEGACY_BAGREC`.

## One scare worth recording

Arming the platform once browned out the Pi (SSH + GUI + vision all died at
once, clock dipped to 1000 MHz at 58 °C). It was **power, not code** — the
PSU/cable is marginal under the motor-arming current spike. A power-cycle
recovered it; an ODrive re-home cleared the resulting calibration garbage
(which had shown up as a one-off rms 210). If you raise leg speed/current,
keep the power margin honest.

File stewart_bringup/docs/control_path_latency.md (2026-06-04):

# Control-path latency map: detection → platform moved

**Added 2026-06-04.** Traces every latency source from a photon hitting
the sensor to the platform actually tilting toward the target, **grounded
in the code** (file:line), with **where each value comes from** so nobody
has to guess. Supersedes the vision-only `oak_latency_map.md` for the
end-to-end picture. Built after demo bags exposed that I had been quoting
the wrong latency number — see §1.

## 1. The correction up front: two different "latency" numbers

The OAK publishes **three** latency figures (`oak_driver._log_pipeline_health`,
oak_driver_node.py L2008–L2075). They are NOT interchangeable:

| Field | Frame it measures | Measured (demo bags 2026-06-04) | Is it the control path? |
|---|---|---|---|
| **`v0_lat_ms`** (`/oak/health[idx]`) | the **active detector's** frame (cv2 on 320×180, or the on-device NN) — set from the detection's capture stamp, L2391 (NN) / L2471 (cv2) | **~56–62 ms** | **YES — this is what feeds the controller** |
| `jpeg_lat_ms` | the MJPEG GUI live-feed frame (L2325) | ~100–150 ms | no — GUI feed |
| `/oak/latency_ms` (topic) | the rgb-raw drain frame (L2323) | ~124 ms | no — GUI/debug frame |

**I had been citing `/oak/latency_ms` (~120 ms) as the control latency. It
isn't.** The controller's vision input rides `v0_lat_ms` ≈ **56 ms**, even
on cv2. The GUI "circle" trails because it rides `jpeg_lat_ms` (~100 ms)
**plus** rosbridge + browser render — which is why it looks ~2–3× worse
than the loop actually is. (Verified: cv2 and YOLO bags both ~56–62 ms
`v0_lat_ms`; switching backends did **not** change control latency.)

## 2. The full chain (capture → platform tilting)

| # | Stage | Latency | Rate | Value & where it's set | Measured? |
|---|---|---|---|---|---|
| 1 | **Exposure integration** | 1.5 ms | — | `OAK_EXP_US=1500` — `stable_bot.service` env | config |
| 2 | Sensor readout + ISP + on-device detect + USB transport | **bundled in `v0_lat_ms` ≈ 56–62 ms** | — | pipeline in `oak_driver._build_pipeline` | **measured** (`/oak/health`) |
| 2b | **New-detection cadence** | — | **~12 Hz** (`v0_pub_hz`) → a fresh sighting every ~80 ms | cv2 host loop / NN rate | **measured** |
| 3 | `ball_localizer` reproject pixel→plane mm | ≤ 16 ms (tick) | **60 Hz** | `create_timer(1/60, _tick)` — ball_localizer_node.py L162 | code |
| 4 | `ball_kf` predict/update → `/ball_state` | ≤ 10 ms | 100 Hz predict | `DT=1/100` — ball_kf_node.py L39 | code |
| 5 | BALL_TRACK reads state, computes tilt (+ lookahead) | ≤ 1 tick | **200 Hz** (5 ms) | `ctrl_period_s = 1/level_loop_hz`, default `LEVEL_DEFAULT_HZ=200` — stewart_control_node.py L1051, L183 | code |
| 6 | `_do_set_pose → _compute_motor_targets → feeder.set_pos_targets` | ~0 (sets array) | — | L2789, L939 | code |
| 7 | **ODriveFeeder streams `Set_Input_Pos`(target, vel_ff)** | **≤ 20 ms** | **50 Hz** | `ODriveFeeder period=0.02` — L897 (hardcoded, not plumbed) | code |
| 8 | CAN transmit | ~0.1 ms/frame | — | 1 Mbps — `install_on_pi.sh` / `global_limits` | code |
| 9 | **ODrive pos loop → leg slews to target** | **leg-vel-cap bound** (see §3) | — | `vel_limit = soft_max_vel*1.5` — L1476; `INPUT_MODE_PASSTHROUGH` L1518; `vel_ff` L1021 | code |
| 10 | Motor torque + platform inertia + settling | mechanical | — | hardware | — |

**Vision half** (capture → fresh `/ball_state`): ≈ `v0_lat_ms` (56 ms) +
localizer tick (≤16) + KF (≤10) ≈ **~70–80 ms**, refreshed at the **~12 Hz**
detection cadence (the 60 Hz `/ball_xy_mono` is reprojection, not new info).

**Control half** (`/ball_state` → platform actually tilting): control tick
(≤5) + feeder (≤20) + CAN (~0) + **leg slew** (§3) + mechanical.

## 3. The actuation stage — your "max turn speed" (the missing piece)

This was never in the latency budget and is a real, tunable lag:

- The legs run in **position mode, passthrough** (no trapezoidal profile),
  with an ODrive **velocity ceiling** `vel_limit = soft_max_vel × 1.5`
  (stewart_control_node.py L1476).
- `soft_max_vel` default **1.0 turn/s** (`global_limits.yaml`
  `default_soft_max_leg_vel_turns_per_sec`), hard ceiling **4.0 turn/s**
  (`hard_max_leg_vel_turns_per_sec`). At 71 mm/rev that's **~106 mm/s** leg
  speed at the default cap.
- **Set live by the GUI** vel-cap slider (range 0.1–2.0) →
  `cmd: set_speed_cap` → `self.soft_max_vel` (L2473). So the operator can
  throttle how fast the platform can move.
- The feeder adds **velocity feed-forward** (`vel_ff = Δtarget/Δt`, L1005,
  L1021) so the legs *lead* a moving target instead of chasing it —
  this is what keeps tracking error low despite the 50 Hz feeder.
- A separate **tilt-rate** envelope exists in `global_limits.yaml`
  (`hard_max_tilt_rate_deg_per_sec 15`, soft default `8`). In BALL_TRACK
  the per-tick growth cap is `tilt_slew_up_deg_per_s = 100` (effectively
  off, ball_track_gains.yaml), so the **binding actuation limit is the leg
  velocity cap**, not the tilt-rate cap.

**Why it matters:** a tilt *reversal* to brake the ball (e.g. +1.2° → −1.2°)
is a real leg displacement at ≤106 mm/s — tens of ms — on top of the 20 ms
feeder quantization and mechanical settling. So the **actuation half is a
similar order to the vision half**, and lowering the vel cap (or the
1.2° tilt cap) directly slows the platform's ability to respond.
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

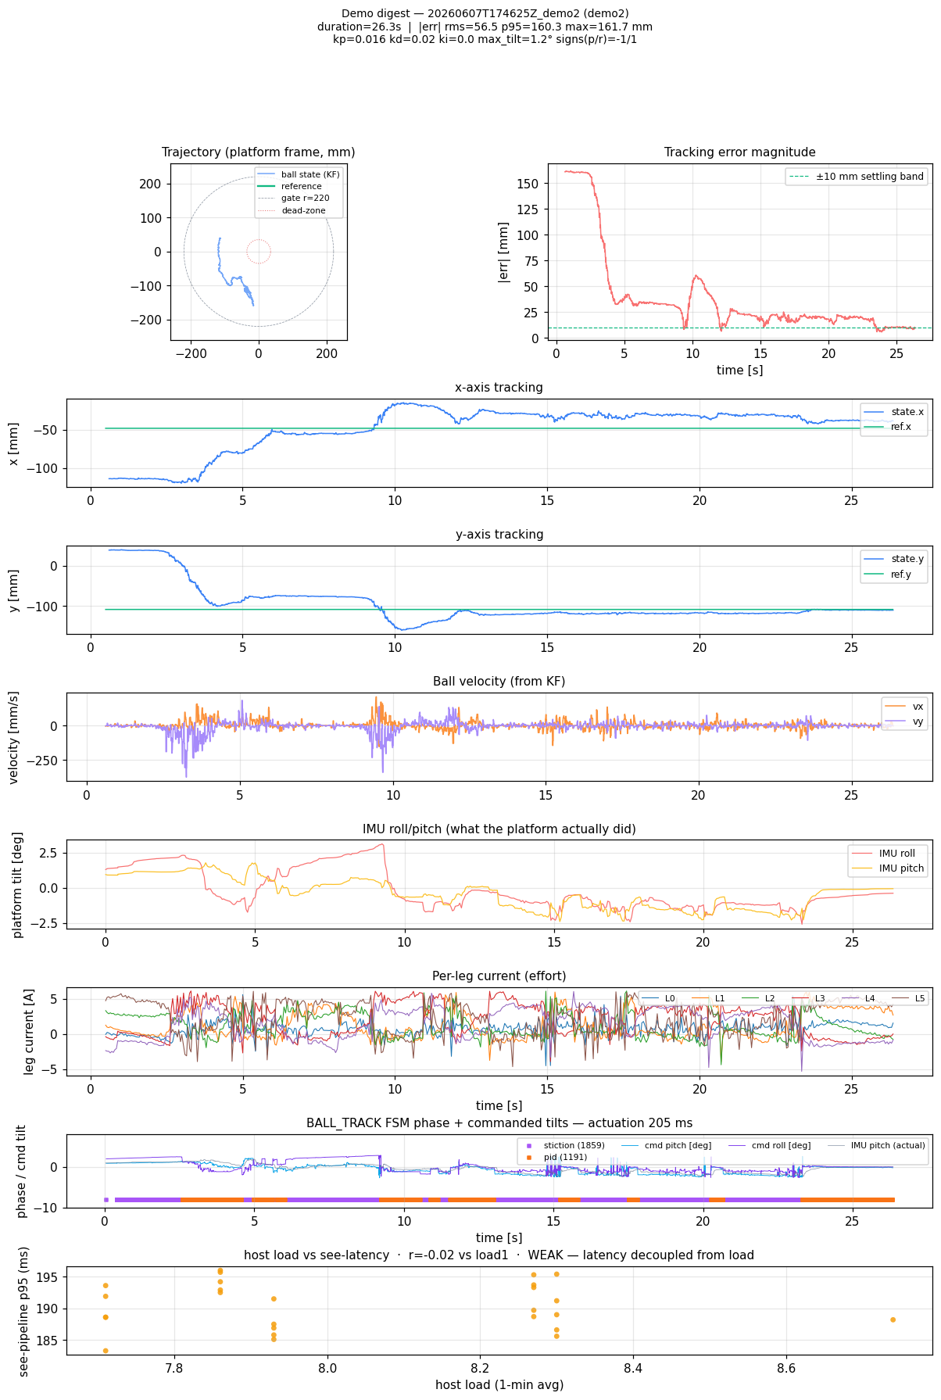
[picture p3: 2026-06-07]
tuning_data/20260607T174625Z_demo2/digest.png

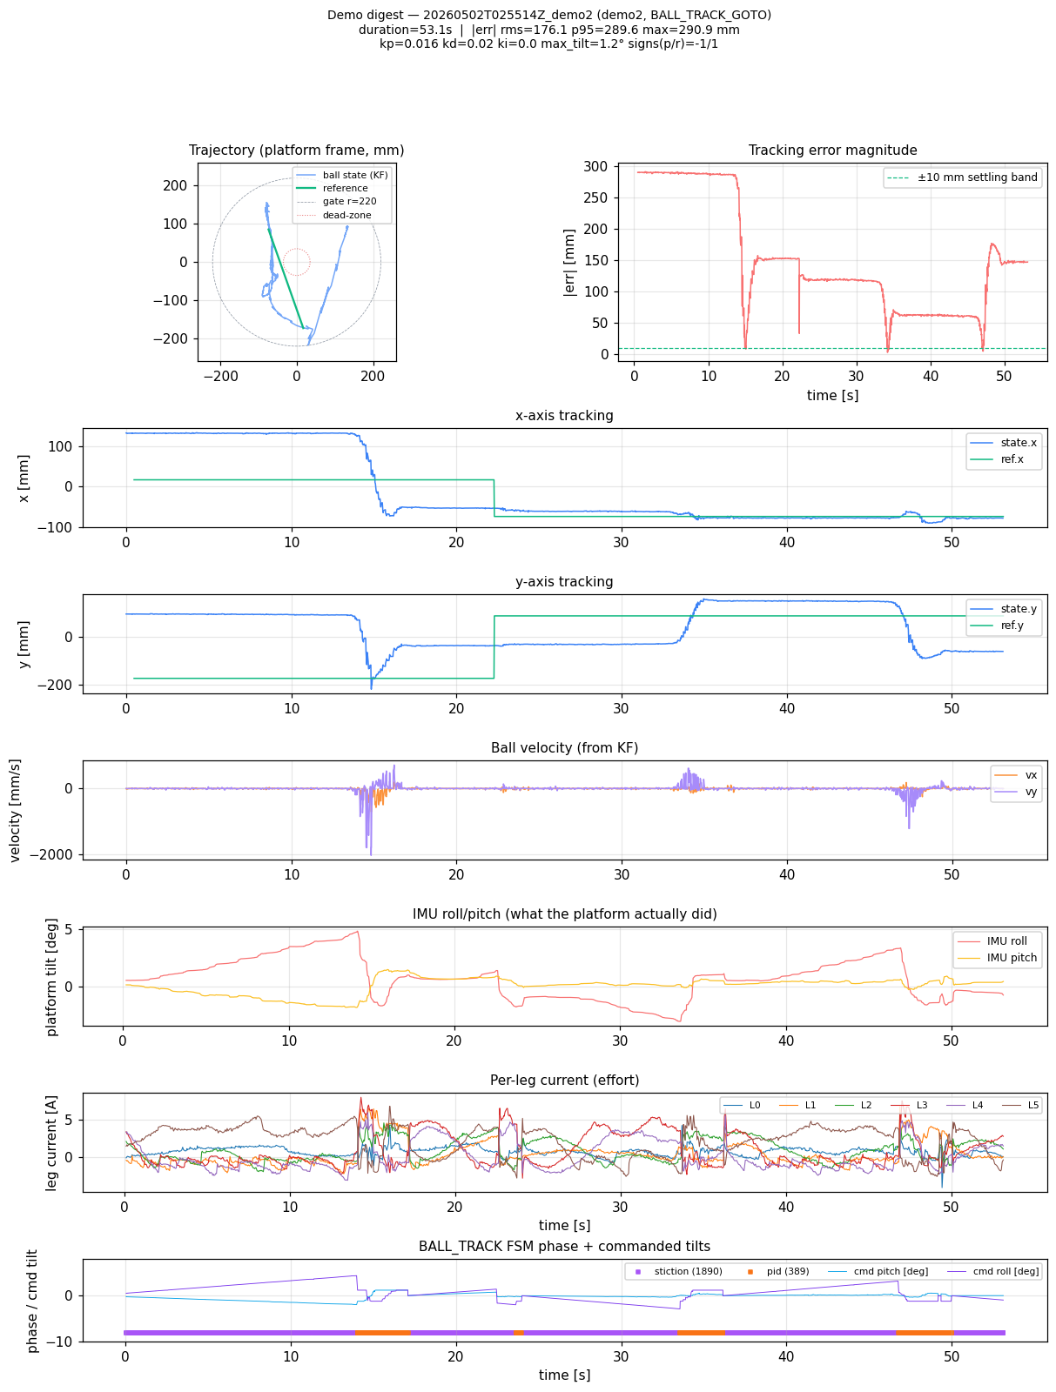
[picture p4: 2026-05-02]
tuning_data/20260502T025514Z_demo2/digest.png

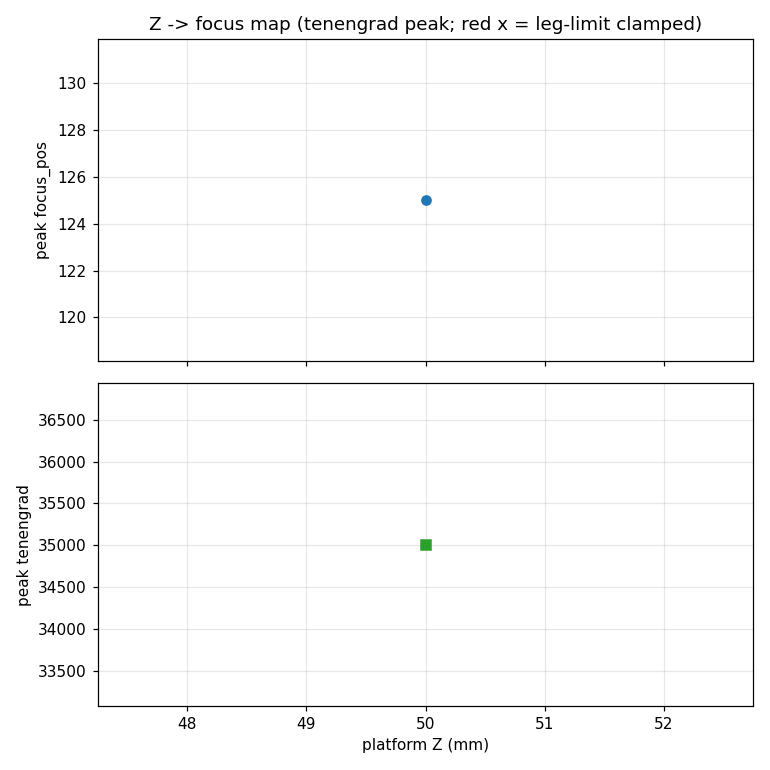
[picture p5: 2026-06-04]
tuning_data/20260604T162443Z_zfocusmap/z_focus_map.png

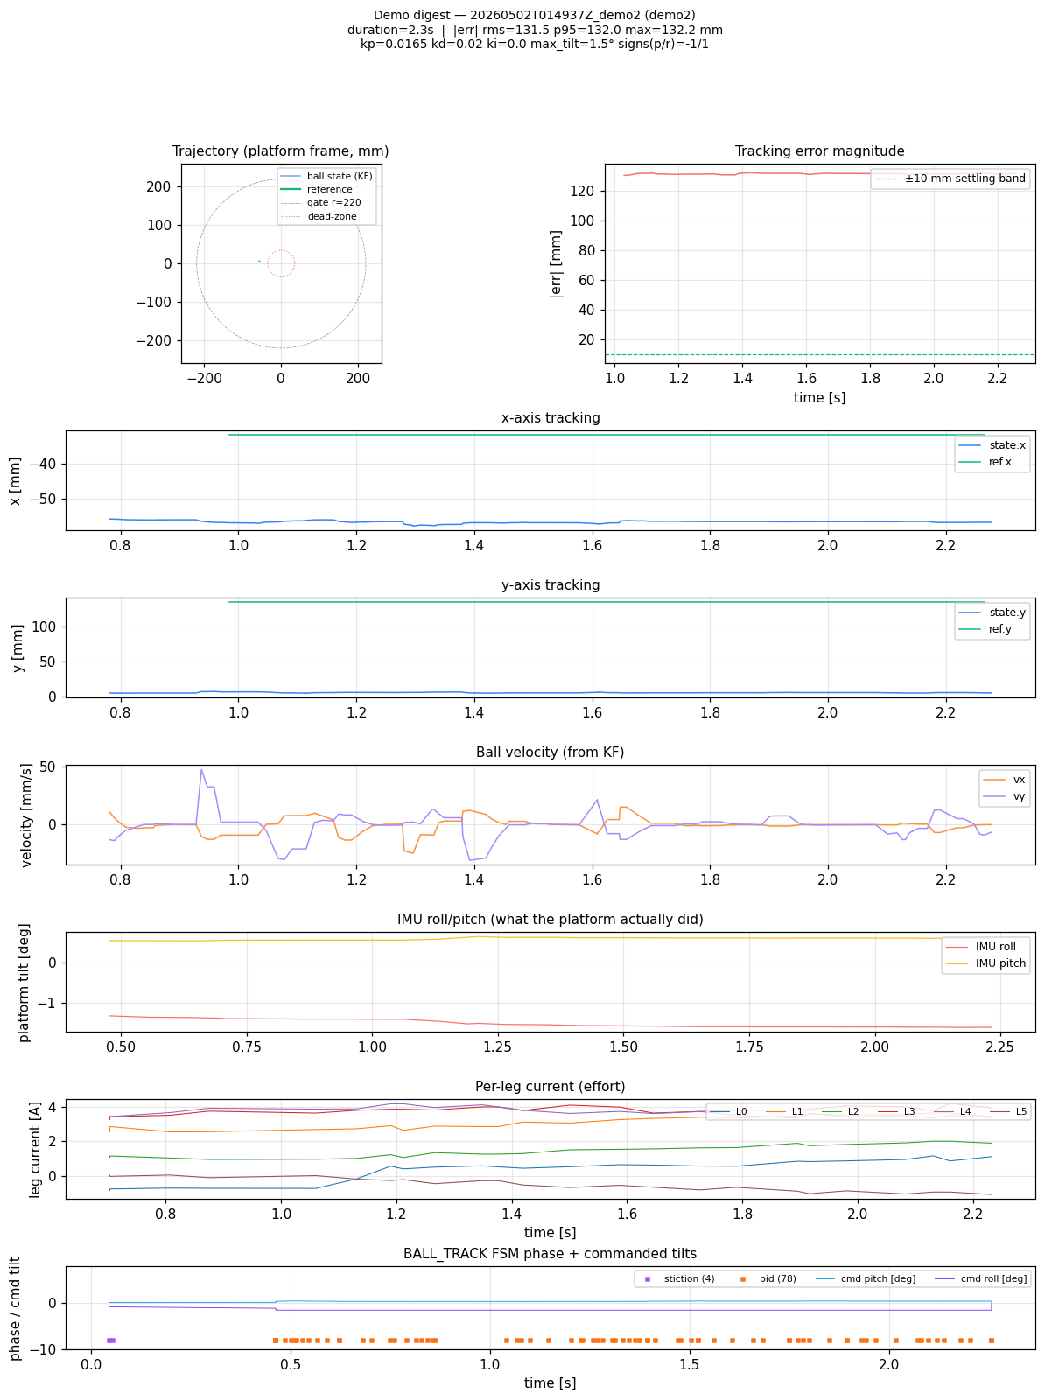
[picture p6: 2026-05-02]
tuning_data/20260502T014937Z_demo2/digest.png

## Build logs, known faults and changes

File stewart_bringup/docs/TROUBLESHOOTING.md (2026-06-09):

# Troubleshooting

Consolidated fixes for issues encountered during bring-up. Organized
from most-common to least-common. The one-command fix at the top is the
right answer about 70% of the time.

---

## The one command

```bash
python3 ~/ros2_ws/src/stewart_bringup/scripts/reset_stewart_stack.py --launch --verify
```

Kills everything, frees port 9090, restarts the ROS daemon, relaunches
the bundle, polls `/status` for 20 s, and prints a verdict. If it says
`/status IS publishing`, you're good; close and reopen the browser tab.

---

## Symptom → fix

### GUI shows "(connected but no /status message received yet…)"

1. Run the one command above.
2. If verify still fails, check the log tail it prints. Usually one of:
   - **"Address already in use" on 9090** → a zombie rosbridge. The
     script's step 0 (`fuser -k 9090/tcp`) fixes this. Re-run.
   - **No `stewart_control_node ready` line** → the control node is
     crashing during init. Run it standalone to see the traceback:
     `ros2 run stewart_bringup stewart_control_node`.
   - **Node is ready but CLI can't see topics** → DDS env mismatch.
     Make sure the launch file does NOT set `ROS_LOCALHOST_ONLY` or
     `ROS_AUTOMATIC_DISCOVERY_RANGE`. (See memory
     `feedback_ros2_discovery_env.md`.)

### ODrives pulsing red

Latched error state. Open the GUI errors panel, click **Read now** to
see which flag:

| Flag | Meaning | Fix |
|---|---|---|
| `WATCHDOG_TIMER_EXPIRED` | host stopped sending commands | Click **Clear all**. Usually caused by killing the node while armed; the feeder-before-arm pattern prevents it. |
| `CURRENT_LIMIT_VIOLATION` | motor wanted more current than cap | Raise current slider in Motor Limits panel. |
| `SPINOUT_DETECTED` | motor stalled / fought mechanical bind | Clear errors, reduce load or current, investigate mechanics. |
| `DC_BUS_OVER_CURRENT` | PSU can't sustain demand | Lower current limit, check PSU sizing. |

If **Clear all** doesn't work (drives don't respond), the CAN bus is
off. Click **Soft-reset CAN bus** — if that times out,
physically unplug + replug the USB-CAN cable.

### One leg under-actuates — leveling "freezes", real Z falls short

**Symptom.** One leg lags its commanded position; the hold-level loop's
`corr_roll`/`corr_pitch` wind up and can rail to `max_corr` (the platform
"freezes" while trying to level); a pure-Z heave moves some legs ~2× others;
and the real platform Z ends up well below the commanded/GUI Z. The deficit
grows the harder you push.

**Diagnose.** Record a hold-level (or any) bag with the demo recorder and
digest it. The `level_loop` block in `digest.summary.json` reports, per leg,
`track_err_absmax_turns` (commanded `motor_target` − actual `leg_enc`),
`vel_absmax_tps`, `iq_absmax_a`, and names the `worst_tracking_leg`. The bad
leg shows a **large tracking error and ~half the peak velocity of the others
but NORMAL current.** That combination — work in, no motion out, current *not*
elevated — means the motor is turning but the leg isn't following. (A seized /
high-friction leg would instead *spike* current and usually latch
`SPINOUT_DETECTED`.)

**Rule out the cheap thing first** (drive-config asymmetry, no disassembly):
`journalctl -u stable_bot -b | grep -i wL_FF` (did torque-FF fail to write on
that leg?), and with the stack stopped, `set_odrive_feedforward_via_can.py
--status` to compare that leg's `wL_FF_enable` / `current_soft_max` / gains to
the others. If the config matches the others, it's **mechanical**.

**Root cause seen 2026-06-09 (leg 5):** the **Dyneema actuation thread had
slipped off a pulley**, so the motor spun and drew normal current but the leg
didn't actuate. **Fix: power down and re-seat the Dyneema thread on the
pulley** (check thread routing/tension on the other legs while you're in
there). Confirm by re-digesting a level bag — the leg's `track_err` should
drop to the others' (~0.1–0.3 turns), the standing `corr` collapses, and the
freeze / Z-shortfall is gone.

### CAN "Transmit buffer full"

The kernel TX queue is saturated because sends are failing (ODrives in
error state aren't ACKing). Cycle:

```bash
sudo ip link set can0 down
sudo ip link set can0 up type can bitrate 1000000
```

If that returns `Timer expired`, the gs_usb adapter itself is wedged —
physically unplug USB, wait 3 s, replug, and re-`usbipd attach` if on
WSL2.

### `ros2 node list` hangs

ROS 2 daemon is stale. Either:
- GUI Diagnostics → **Restart ros2 daemon**, or
- Terminal: `ros2 daemon stop && ros2 daemon start`.

### Xsens IMU "No MTi device found"

USB not attached. On WSL2: `usbipd attach --wsl --busid <X-Y>` from
Windows admin PowerShell. On Pi: verify the udev symlinks exist:
`ls /dev/imu_mti630*`. If they don't, check `dmesg | tail` for USB
enumeration errors.

### Rolling ball rolls right off the disk

Open-loop + static friction is fundamentally hard. In order of
effectiveness:

1. **Physically flick the ball** before pressing Play so it's moving
   when the routine starts.
2. Swap to a **smoother surface** (acrylic, glass, polished aluminum,
   or a sheet of paper taped to the carbon fiber).
3. Use a **heavier / more-dense ball** (glass marble, ball bearing).
4. Tune the routine: smaller `radius_m`, `max_tilt_deg`, try the
   `tilt_multiplier` slider.
5. **Give up and use the stabilization demo** — hold level, tilt the
   base by hand, top stays flat. Same platform, more impressive
   showcase, works every time.

### Browser shows "Can 'Upgrade' only to 'WebSocket'"

You've navigated to `http://localhost:9090` (the rosbridge port).
Navigate to `http://localhost:8080/` instead (the GUI server port).

### Everything seems fine but no motor movement

Drives armed but at the wrong mode. Check:
- GUI **per-leg arming** row: each checkbox should be ticked (green)
  for velocity mode, or use the main **Arm** button for position mode.
- Motor limits slider isn't at minimum.
- For per-leg jog (+ / − buttons), the leg auto-switches to pos mode.
  If it doesn't respond, check the errors panel — might be latched.

### GUI buttons do nothing but /status is flowing

`/control_cmd` messages aren't reaching the control node. Usually a
rosbridge reconnect fixes it:
- GUI Diagnostics → **Reconnect rosbridge**.
- Or: close the browser tab completely, reopen to
  `http://localhost:8080/`.

### Pi: SSH refused / `stablebot.local` doesn't resolve

- Phone hotspot must be ON when the Pi boots, with the SAME SSID and
  password you baked into the SD card. Case-sensitive.
- Give it ~60 s after power-on.
- mDNS (`.local`) may be blocked on phone hotspots — check the
  hotspot's "connected devices" list and SSH to the raw IP instead.

### Pi: launch comes up but IMUs fail with "No MTi device"

udev rules don't know your serial numbers yet. Check:
```bash
udevadm info -a /dev/ttyUSB0 | grep serial
```
Copy the serial(s) into `/etc/udev/rules.d/60-stablebot.rules`,
`sudo udevadm control --reload-rules && sudo udevadm trigger`.

---

## Recovery hierarchy (when to escalate)

1. Close browser tab completely, reopen → fixes ~30% of GUI hangs
2. **Reconnect rosbridge** button → fixes websocket wedges
3. **Restart ros2 daemon** button → fixes CLI hangs
4. **Hard reset stack + (Re)launch stack** buttons → fixes zombie processes
5. `reset_stewart_stack.py --launch --verify` in terminal → the big hammer
6. `reset_stewart_stack.py --nuclear --launch --verify` → cleans stale python3 procs
7. Physical USB cycle + `usbipd attach` (WSL2) or replug (Pi) → last resort
8. Power-cycle the ODrive supply → ODrives won't clear via CAN

If any step before a later one is usable, skip to it. Earlier steps are
less disruptive.

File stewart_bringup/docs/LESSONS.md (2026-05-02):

# Stable-Bot — compiled lessons learned

Everything I learned getting this thing from "scripted open-loop
rolling ball" to "click-to-goto with 0.5 mm tracking error." Terse
on purpose. Each bullet is a rule that prevents a specific mistake
I made or saw made; the parenthetical is the doc with the longer
story if you want it.

---

## ODrive / motors / CAN

- Every parameter the loop depends on must be (a) persisted to flash
  via the configurator AND (b) re-asserted at runtime on every
  level-on. Neither alone is enough — flash gets overwritten by
  recalibration, runtime gets reset by disarm.
  (level_loop_lessons_learned.md §1)
- `wL_FF_enable`, `control_mode`, `current_soft_max`, `vel_limit` all
  silently revert to factory defaults via the WebGUI's "Run
  Configuration Script." Same recurring bug shape.
- All 6 ODrives must be on the **same firmware build**. Different
  builds have different endpoint tables; CAN SDO writes to one
  endpoint id can be the wrong field on a sibling drive.
  (memory: feedback_odrive_firmware_uniformity)
- Don't `time.sleep()` between `Set_Axis_State=8` and the first
  motion command. The watchdog disarms silently with
  `active_errors=0x01000000`. (memory: feedback_odrive_watchdog)
- Drive showing `0483:df11` in dmesg is in STM ROM DFU, not bricked.
  Flip the physical RUN/DFU switch on hw 4.4 + power-cycle.
  (memory: feedback_odrive_pro_dfu_run_switch)
- `gs_usb` USB-CAN adapter (VID:PID 1d50:606f) is in the WSL2 kernel
  built-in. Use the netlink bring-up path, not slcand.
  (memory: project_jugglebot_can_adapter)
- Set `vel_limit` at three independent layers (firmware, Python CAN,
  GUI sliders) — the redundancy is the point.
- ODrive's Python lib (0.6.10) has no CAN transport. Use Tx_SDO
  via python-can. Endpoint metadata is at
  `parent._<name>_property._info` in `sync_tree`, not on the leaf.
  (memory: feedback_odrive_can_param_access)

## ROS 2 / WSL2 / Pi

- Don't set `ROS_LOCALHOST_ONLY=1` or
  `ROS_AUTOMATIC_DISCOVERY_RANGE=LOCALHOST` in launches — silently
  hides topics from CLI tools that don't set the same vars.
  (memory: feedback_ros2_discovery_env)
- Pi build env: bashrc only sources the overlay → PYTHONPATH empty
  → `ament_package` import fails. Source `/opt/ros/kilted/setup.bash`
  first. ntrip won't build (broken upstream); apt name is
  `ros-kilted-ament-package` not `python3-ament-package`.
  (memory: feedback_pi_build_env)
- `pi_deploy.sh` is the only deploy path that works:
  `--packages-select jugglebot_interfaces stewart_bringup` (skip
  ntrip), then restart **both** `stable_bot.service` AND
  `stable_bot_gui.service`. Pull alone is not enough — the install/
  tree won't reflect symlink-source changes without colcon build.
  (memory: feedback_pi_pull_restart_recipe)
- USB devices reach WSL via `usbipd-win`, not natively. `attach
  --wsl --busid <X>` from a Windows admin shell per session;
  `bind` is one-time.
  (CLAUDE.md)
- SQLite databases belong on the Linux side (`~/...`), not under
  `/mnt/c/...` — FTS5 trips over Windows-mount I/O.
  (CLAUDE.md)
- Pi 5 USB-A 3.0 is the *blue* port. USB-C is power-only.
  (closed_loop_ball_demos_usage.md)

## Vision pipeline

- `setFps(N)` is a *ceiling*, not a floor. Auto-exposure is allowed
  to pick any integration time up to the frame interval; in dim
  rooms it picks 30-67 ms and the framerate floor-divides. Manual
  exposure (`setManualExposure(8000, 800)`) + a real light source
  takes you from 4 Hz to 30 Hz with the same code.
  (controls_journey.md)
- `setAutoExposureLimit` should work but doesn't on depthai 2.32 +
  current OAK firmware. Use `setManualExposure`.
- USB sustained throughput on OAK-D Pro AF is ~30-50 MB/s, far
  below the theoretical 400 MB/s SuperSpeed. At 540p × 1.5 MB/frame
  this caps at 20-30 Hz — that's the real ceiling, not the FPS
  setting.
- IR projector dot-speckle on mono cameras breaks ArUco corner
  detection. Run ArUco on the RGB stream (IR-cut filter); mono is
  for stereo only when IR is on.
  (memory: feedback_oak_ir_vs_aruco)
- OAK's default stereo cutoff is ~632 mm. Platform sits at ~600 mm.
  `setExtendedDisparity(True)` doubles the disparity range and
  halves the minimum to ~316 mm.
  (vision_control_tuning_lessons.md)
- Stereo on smooth surfaces (carbon fiber + vinyl + foam ball + IR)
  fails predictably: 80%+ "valid" pixels but median height pegged
  at the wrong sign. Either add texture or abandon stereo for
  platform-tracking.
- HSV detection on a moving ball is brittle. Each ~2× of exposure
  time roughly doubles per-pixel light AND doubles motion smear.
  Trade-off: shorter exposure + brighter ambient is the dominant
  strategy.
- YOLOv8n had ~20% better stationary-frame benchmarks than cv2 HSV
  but lost the ball almost immediately during demos with motion.
  **Don't trust offline accuracy benchmarks for closed-loop
  control quality. Always A/B with the runtime backend selector.**
  (step_id_tuning_lessons.md TL;DR #3)
- rosbridge JSON-array serialization of `uint8[]` inflates 7×; JPEG
  decoding via `String.fromCharCode + btoa` blocks the JS event
  loop. Both compound. Fixes: lower JPEG quality at the publisher,
  throttle at the bridge, Blob URLs at the browser.
- End-to-end vision-to-command latency is ~100 ms (capture, USB,
  KF, control loop). At 300 mm/s ball speed that's 30+ mm of drift.
  Use latency lookahead in the controller (`ex_lead = ex + edot · Td`).

## Frames & IK

- The geometric IK in `_compute_motor_targets` is wrong by **45-62°
  rotation per leg** vs the empirical Jacobian. Mean magnitude
  error: 130% on roll, 450% on pitch. Tuning gains on top of a
  broken IK is wasted effort.
  (level_loop_lessons_learned.md §2,
   demo2_shipping_journey_2026-05-02.md TL;DR #1)
- ArUco frame ≠ IMU body frame. Procrustes fit between them on
  this hardware shows a ~155° rotation. Sign-flips on individual
  axes cannot compensate — only a 2D rotation can.
  (controls_journey.md, vision_control_tuning_lessons.md)
- The `aruco_imu_alignment.yaml` rotation must be applied to **both**
  `/ball_state` (in `ball_localizer_node`) AND `/ball_ref` (in
  `ref_generator_node`). The controller subtracts ref from state;
  if they're in different frames, the result is rotated garbage.
  (controls_journey.md)
- Right-hand-rule rotations are not symmetric across axes.
  `Ry(+p)` tilts +X edge DOWN (ball slides +X). `Rx(+r)` tilts +Y
  edge UP (ball slides −Y). `pitch_sign = -1, roll_sign = +1` is
  the correct combination given the standard math convention. Don't
  trust docstrings against formulas — derive from the rotation
  matrices.
  (controls_journey.md)
- `_do_set_pose` and the level loop must use the same IK path. If
  one uses `empirical_ik` and the other doesn't, every command
  through the wrong path is silently rotated by the platform's
  leg-mount frame error.
  (demo2_shipping_journey_2026-05-02.md TL;DR #1)
- For BALL_TRACK on a tilted plate: rotate the platform UNDER the
  ball, not about its geometric center. `z_cmd = z_hold + px·sin(p)
  − py·sin(r)` keeps the ball's world-frame height invariant under
  tilt commands.
  (vision_control_tuning_lessons.md)

## Control theory — PID, bang-bang, stiction

- **`max_tilt` is the in-flight damping cap, not the
  controller-can-ever-output cap.** Stiction breakaway needs higher
  authority than in-flight damping. Decouple via
  `stiction_ramp_max_deg`.
- **Two physically-distinct tilt thresholds, not one.** Stiction
  breakaway `θ_s` (~2.14° on this hw, hardware property) and
  orbital braking `θ_orb` (depends on instantaneous ball state).
  At rim with v=500 mm/s, `θ_orb ≈ 7.3°`. `max_tilt < θ_orb` means
  the controller is physically incapable of recovering from that
  orbit. Recommended floor: `max_tilt = max(θ_s + 2.5, 8.0)`.
  (step_id_tuning_lessons.md TL;DR #1)
- **PID Kd × v_noise dominates direction when Kd is non-trivial.**
  Math: Kd dominates Kp when `|v| > (Kp/Kd) · |err|`. With raw
  noisy KF velocity reading 60+ mm/s on a stationary ball, this
  threshold is hit during normal motion. Filter the velocity that
  Kd reads (`kd_v_tau_s` LPF) — orbital motion (~1 Hz) passes,
  frame-rate noise (>5 Hz) gets attenuated 20-30 dB.
  (demo2_shipping_journey_2026-05-02.md TL;DR #2)
- **Bang-bang has no tangential damping.** FSM phase logic is
  keyed on `v_toward` (radial). For an orbiting ball, `v_toward ≈ 0`
  → FSM picks ACCELERATE → tilts toward target → adds inward
  force only → tangential velocity is conserved → orbit persists.
  PID's `Kd × v` opposes all directions; that's why PID kills
  orbits and bang-bang doesn't.
  (demo2_shipping_journey_2026-05-02.md TL;DR #3)
- **Slam-to-max stiction relief is wrong on low-friction
  hardware.** Gives the ball more energy than the controller can
  damp. Use a slow ramp from `θ_s + small_margin` upward instead;
  ball breaks loose at near-zero velocity.
- **`ramp_rate × timeout` must exceed `ramp_max - ramp_start`.**
  Otherwise the stiction ramp times out before reaching its
  configured ceiling. Operator's `0.35 × 8 = 2.8°` couldn't reach
  `5.0°`. Hours of tuning vanished into this single equation.
  (demo2_shipping_journey_2026-05-02.md TL;DR #5)
- **Position-delta is far cleaner than velocity-threshold for
  binary detection.** A stationary ball jitters by 1-2 mm in
  position; velocity is the derivative and amplifies that to
  30-60 mm/s. Use 5-10 mm position delta from a snapshot for
  "did the ball actually move." (TL;DR #4)
- **Hysteresis on motion detection: LPF + consecutive-tick
  counter both required.** Single-tick noise spikes are filtered
  by hysteresis; sustained noise events are filtered by LPF.
  Each on its own is insufficient on this hardware.
- **Cascade-bypass tradeoff**: `BALL_TRACK` commands tilts
  directly via `_do_set_pose` (no inner level loop). Faster
  transient response, but plant biases (leg backlash, IK
  approximations, gravity sag) that the level loop used to
  absorb now show up as ball-position bias. Compensated by the
  outer integrator — slower bias rejection, faster transient.
  (step_id_tuning_lessons.md)
- **Closing the inner tilt loop on IMU is essential UNLESS the
  outer loop is bandwidth-limited by it.** Original design used
  level-PI as the inner loop tracking `current_rpy`. Level-PI's
  500 ms step response capped BALL_TRACK at `ωn < 1 rad/s`. The
  analytic recommendation engine's preferred `ωn = 4 rad/s` was
  incompatible with the cascaded plant. Bypass was the right call.
- **Vision-latency lookahead** (`ex_lead = ex + edot · Td`) is
  mathematically equivalent to bumping Kd by `Kp · Td`. Restores
  the predicted closed-loop poles when an analytic Kp/Kd pair was
  computed assuming zero dead-time.
- **Plant ID has 30-50% CV** across replicates on this hardware,
  driven by vision noise. Don't trust single-trial recommendations.
  (step_id_tuning_lessons.md TL;DR #4)

## Stiction & friction (low-μ-specific)

- `θ_s` measured by STEP_ID's stiction phase varies across the
  deck. Set `stiction_ramp_start_deg` above the measurement and
  let the ramp climb from there.
- `μ_s = 0.037` (foam on vinyl) is too low for friction alone to
  decay tangential velocity. Bang-bang's COAST relies on friction
  decay; on this hardware it doesn't work.
- Static friction overcoming = high tilt; kinetic friction (rolling
  ball) = much lower. Asymmetric `accel_tilt_deg` vs
  `brake_tilt_deg` captures this — a moving ball needs MORE tilt
  to brake than a still ball needed to start.
- `max_tilt` must be **above** `θ_s` so PID can *maintain* motion
  between stiction-ramp pulses, not just below the runaway
  threshold. Sweet spot on this hw: 1.2-1.5°.
  (demo2_shipping_journey_2026-05-02.md "max_tilt = 1.0 killed PID")
- "Pulse-coast-pulse" walker pattern beats "one big push" on
  low-friction hardware. Each ramp pulse just barely breaks
  stiction → ball moves a small distance → PID damps → ball stops
  → next pulse fires. Tunable via `stiction_pos_delta_mm` and
  `stiction_ramp_timeout_s`.
- Don't blame friction for level-loop drift before checking
  controls. Operator has held ±0.1° on this hw before; track-loss
  on previously-working configs is a control regression, not
  mechanical stick-slip.
  (memory: feedback_dont_default_to_friction_diagnosis)

## Vision noise — specific patterns

- Single-frame V0 false-positives spike `vx, vy` to 4000+ mm/s on
  a foam ball that physically tops out at 800. `Kd × v_spike`
  saturates `max_tilt` in random directions. Cap `|v|` at the
  physical max before applying Kd
  (`BT_MAX_BALL_VEL_MM_S = 800.0`).
- Trajectory looks "flat then jumps" when V0 loses the ball during
  fast motion (HSV failure under motion blur) and re-acquires at
  a new position 50+ mm later.
- `/oak/health.v0_arr_hz ≈ 27`, `v0_pub_hz ≈ 12.5`. Publish rate is
  capped somewhere downstream; if you can lift it to match
  arrival, effective vision latency halves.
- Off-platform false positives: tightening HSV S/V bounds for
  motion-blur tolerance loosens the discrimination from off-deck
  shadows. Tighten the platform mask radius (0.220 → 0.190 m)
  to compensate.

## Tooling & methodology

- **Hand-tuning with good comparison tools beats auto-tuning.**
  Auto-tuner (Bayesian/hill-climb) failed: 27 trials, 0 acceptances
  because random-target fitness noise > gain effect. Operator hand-
  tuning + `compare_demo_bags.py` succeeded by sorting all runs
  by metric and reading the gain-vs-outcome correlation off the
  table.
- **Bag-driven tuning beats guess-and-check.** Live-editable
  gains via the GUI + auto-recorded demo bags + auto-digest
  produces a tuning timeline in `git log`. Every gain change
  becomes a diff, every run a digest commit.
- **Phase telemetry is mandatory for FSM debugging.** Without
  `/ball_track/diagnostic`, "stuck in ACCEL forever (stiction)"
  and "rapidly chattering ACCEL↔COAST↔BRAKE (thresholds wrong)"
  both look like "ball doesn't track" in the bag.
- **Find code-path inconsistencies before tuning gains.** Hours
  spent tuning while a frame-rotation IK bug silently corrupted
  every tilt command. **Always grep "X is used in N places — does
  it use the same auxiliary state in each?" before assuming the
  algorithm is correct.**
  (demo2_shipping_journey_2026-05-02.md durable lesson #1)
- **Velocity is noisier than position by `1/dt`.** For binary
  detection, use position. For continuous control, use filtered
  velocity. For lookahead, use either.
- **Live KF tuning is downstream**. No amount of Q/R tweaking
  helps if the underlying frame is wrong (IK fix) or the
  controller uses stale data (lookahead). Fix the path first.
- **Run the offline non-causal smoother on bags** for "what was
  the ball *actually* doing" — the live KF is causal-only and
  noise-smoothed only from the past. Sav-Gol with window 11,
  order 3 is enough.
- **Compare-script columns must be diff-mode**. Showing the 24
  fields that didn't change across a sweep alongside the 8 that
  did is unreadable. `--diff` mode or it's noise.
- **dates in planning docs absolute, not relative.** `2026-04-18`
  not "Thursday." Future-you doesn't remember which Thursday.
  (CLAUDE.md)

## Architectural decisions that paid off

- **GUI panel for live-editable gains.** Save writes YAML and
  reloads in-memory; no service restart. Iteration cycle drops
  from ~30 s (restart + warm-up) to ~3 s.
- **Two parallel ball detectors (V0 cv2-HSV + depth-blob).**
  Both publish independent topics; the GUI shows them as
  orange/cyan circles for direct comparison. Catches detector
  failures that single-detector A/B can't.
- **Demo-run bag recording with auto-digest.** `/demo/start` →
  rosbag2 → digest script → digest.summary.json + digest.png +
  next_step recommendation. The whole tuning loop is automated
  except for the gain choice.
- **`/oak/health` and `/oak/config` topics bagged every 5 s.**
  Demo bags self-describe — the digest knows what the camera was
  set to during the run. Lets the digest correlate behavior
  changes with config tweaks.
- **`~/.stewart_control_state.json` saves last pose on every
  mutation.** GUI Z sliders read from `/status` on connect, so
  they show the last setpoint instead of `0` after a service
  restart. Removes the "wait, what Z am I at?" class of confusion.
- **Phase code in the diagnostic topic** (`/ball_track/diagnostic`
  field 0). Color-coded phase strip in the digest is what makes
  bang-bang tuneable. Bang-bang's "stuck in ACCEL forever" vs
  "chattering ACCEL↔BRAKE" are the same gross outcome but the
  phase strip distinguishes them in one glance.

## Debugging discipline

- **Frame mismatches are silent.** No combination of `pitch_sign /
  roll_sign` can compensate for a rotated frame. The Procrustes
  fit from an IVA sweep is the only way to know — `det = ±1` and
  `rotation_deg` near a multiple of 90° is the smoking gun.
- **YAML save in the GUI strips comments.** `yaml.safe_dump` emits
  alphabetized keys with no comments. Keep canonical comments in
  this doc; commit them back to the YAML when convenient.
- **`set -u` in bash trips ROS setup scripts.** They reference
  `AMENT_TRACE_SETUP_FILES` etc without defaulting them. Use
  `set -eo pipefail`, drop the `-u`.
- **`pip install` on Ubuntu 24.04 / Python 3.12** is "externally
  managed" (PEP 668). Build artifacts on a dev machine and commit
  them, use `pipx`, or `pip install --break-system-packages` if
  you really must.
- **`stewart_vision` is a separate package from `stewart_bringup`.**
  When editing `oak_driver_node.py` / `ball_localizer_node.py` /
  `ref_generator_node.py` / `ball_kf_node.py`, include
  `stewart_vision` in the colcon build line or the install/ tree
  won't reflect the source change. Multiple 4-hour debug rounds
  traced to this.
- **Two systemd services**, not one. `stable_bot.service` runs
  the ROS launch; `stable_bot_gui.service` runs `gui_server.py`
  directly. After editing `gui_server.py`,
  `digest_demo_bag.py`, or `web/index.html`, **both** services
  must be restarted.
- **CBOR-raw broke rosbridge entirely** on Pi/Kilted. Zero frames
  arrived. Stuck with JSON + Blob URLs + JPEG quality drop.
- **Double-`const` SyntaxError** killed an entire JS bundle once.
  When the rosbridge connection mysteriously dies, check for
  parse errors in `index.html` first.

## Things that didn't work

- **Auto-tuner (hill climb + Bayesian)**: random-target placement
  produced fitness noise larger than gain effect. 27 trials, 0
  acceptances. (`auto_tuning_plan.md` shipped, never paid off.)
- **YOLOv8n as default vision backend**: 20% better stationary
  benchmarks but lost the ball "almost immediately" during demos.
  Reverted. Available via runtime selector.
- **CBOR-raw image transport**: rosbridge on Kilted didn't honor
  it. Reverted.
- **`OAK_FORCE_V1_ARCH=v8` as default**: same story as YOLOv8n.
- **Aggressive `Kp = 0.077`** from a single-replicate G_eff=224.
  Saturated max_tilt = 2.5° at any error > 32 mm. Drove the ball
  into orbital limit cycle every trial. **High Kp without high
  max_tilt is just bang-bang in disguise.**
- **Slam-to-max stiction relief**: kicked the ball at high
  velocity into orbital limit cycles on every restart. Replaced
  with the slow ramp.
- **`max_tilt = 1.0` for safety**: dropped PID below `θ_s` so PID
  couldn't *maintain* motion between ramp pulses. Demo became a
  130-second sequence of 1 mm hops.
- **`control_latency_s = 0.0`**: turned off the lookahead during
  one tuning pass. Phase margin collapsed; the controller saw
  100 ms-stale data and overshot every motion.
- **Self-calibrating depth-blob plane fit**: median of (expected −
  measured) was driven by stereo-edge artifacts at 1.5 m, not the
  platform interior. Removed; trusting ArUco-derived plane
  directly.
- **Setting per-axis hysteresis at 3 ticks (60 ms) only**: not
  enough for sustained vision-noise events of 100+ ms. Needed
  LPF + consecutive-tick combination.

## The two settled runs

- `20260502T025210Z_demo2`: median tail err **0.5 mm**, settled.
- `20260502T030936Z_demo2`: median tail err **4.2 mm**, settled.

Winning gains preserved verbatim in
`demo2_shipping_journey_2026-05-02.md` "The shipping commits"
section. Full configuration in `ball_track_gains.yaml`.

---

The single biggest unlock was finding that `_do_set_pose` and the
level loop used different IK paths (geometric vs empirical
Jacobian, ~55° rotated from each other). One line of code; half a
day to find. Everything else was iteration on top of getting that
right.

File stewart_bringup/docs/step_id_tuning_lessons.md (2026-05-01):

# STEP_ID + Demo 2 controller tuning — lessons learned

A chronological + topical record of the analytic-gains tuning work
done 2026-05-01 to get Demo 2 (click-to-goto closed-loop ball
control) into demo-shippable shape. Continues from the lessons in
`controls_journey.md` (2026-04-30) and `vision_control_tuning_lessons.md`
(2026-04-30 architectural changes). Read end-to-end if you're going
to touch the BALL_TRACK PID, the open-loop plant-ID code, or
anything that subscribes to `/ball_state` for control.

---

## TL;DR — top six lessons

1. **There are two physically-distinct tilt thresholds, and the
   controller's `max_tilt_deg` must satisfy BOTH.**
   - **Stiction breakaway** `θ_s` (≈ 4° on this hardware): the
     minimum tilt to overcome static friction on a stationary ball.
     `tan(θ_s) = μ_s` — pure hardware property.
   - **Orbital braking** `θ_orb`: the minimum tilt to brake a ball
     in a circular orbit at radius `r` and tangential velocity `v`.
     `sin(θ_orb) = v² / (r · g)` — depends on instantaneous ball
     state, NOT friction.
   - At rim with `v=500 mm/s`, `θ_orb ≈ 7.3°`. `max_tilt < 7.3°`
     means the controller cannot recover from that orbit.
   - Recommended floor: `max_tilt_deg = max(θ_s + 2.5, 8.0)`.

2. **Vision noise dominates everything when Kd is non-trivial.**
   Single-frame V0 false-positives can spike `vx, vy` to 4000+
   mm/s on a foam ball that physically tops out around 800 mm/s.
   `Kd × v_spike` saturates `max_tilt` in random directions — this
   is energy injection, not damping. Symptoms: orbital limit
   cycle around the platform rim, peak speeds in the digest CSV
   far above physical limits.
   - Mitigation in PID: hard cap `|edot|` at 800 mm/s before
     applying Kd (`stewart_control_node._ball_track_run`,
     `BT_MAX_BALL_VEL_MM_S`).
   - Mitigation in plant-ID fits: median-filter ball position
     before computing velocity (kernel=5); use 95th-percentile
     instead of `np.max` for peak velocity; linear regression
     of `v(t)` vs `∫θ(τ)dτ` instead of `peak_v / integrated_tilt`.

3. **YOLO is not always better than cv2 HSV — depends on the
   training set.** On this hardware (foam ball, ~600 hand-labelled
   frames, YOLOv6n vs YOLOv8n on Myriad X) the `~20%` benchmark
   accuracy improvement of v8 over v6 *did not* translate to
   reliable detection during fast motion — V1 YOLO completely lost
   the ball "almost right away" during an actual demo. cv2 HSV with
   the platform-mask crop was empirically more robust *for this
   use case* despite being more brittle to lighting in benchmarks.
   - Lesson: don't trust offline accuracy benchmarks for closed-
     loop control quality. Always A/B with the runtime backend
     selector in the GUI before locking in `OAK_V0_BACKEND`.

4. **Single-trial plant ID is not reliable enough on this hardware.**
   Six consecutive STEP_ID sessions on the same hardware in one
   evening produced G_eff = 35, 224, 92, 64, 148±58 (n=3),
   564 (n=1, suspect). 5–10× spread on an in-principle-deterministic
   measurement.
   - Causes (in order of impact): vision dropouts mid-trial,
     stiction breakaway timing varying, fit-window degeneracy when
     motion onset is late, safety cutoff firing inconsistently
     due to vision noise (now fixed via multi-frame consensus).
   - Mitigation: replicated trials with a coefficient-of-variation
     (CV = std/mean) gate. Refuse to recommend gains when CV >
     0.30 across n≥2 replicates. Single-trial sessions surface
     a "single-trial, do not trust" warning instead of silently
     passing.

5. **The cascade architecture caps outer-loop bandwidth at the
   inner loop's bandwidth.** Pre-2026-05-01 design: BALL_TRACK
   commanded `current_rpy`, level-PI tracked it via IMU feedback.
   On this hardware level-PI takes ~500 ms to track a 3° step;
   that fundamentally caps achievable BALL_TRACK `ωn` at < 1 rad/s.
   The analytic recommendation engine's preferred `ωn = 4` rad/s
   was incompatible with the cascaded plant.
   - Fix (2026-05-01): BALL_TRACK now disables level-PI on entry
     and commands tilts directly via `_do_set_pose`. Plant biases
     that level-PI used to absorb (asymmetric leg backlash, IK
     approximations, gravity sag) are now compensated by the
     outer-loop integrator instead. Slower bias rejection but
     faster transient response — net win for ball control.
   - Restore behaviour: `_start_ball_track_loop` saves the level
     state and re-enables it on exit IF it was on before
     BALL_TRACK started. Operator's "level off" choice survives.

6. **`STEP_ID` is a useful methodology even when it can't produce
   a clean recommendation.** Even when CV gates fire and the
   analytic recommendation is refused, the diagnostic outputs
   (`ball_paths_combined.png`, `phase_plane.png`,
   `tilt_timeseries.png`, `plant_gain_fit.png`,
   `step_id_summary.json`) are the right view of the system. The
   per-phase Run buttons (stiction / open-loop / verification)
   let the operator iterate on a single piece without paying for
   the full session. Stiction characterisation alone gives
   `θ_s + μ_s` in 10–25 s — useful even when the operator skips
   plant ID entirely.

---

## The two-tilt-thresholds insight (read this first)

This was the single biggest conceptual confusion during today's
debugging. Several hours wasted before the distinction was clear.

### Stiction breakaway (`θ_s`)

A ball at rest on a tilted plane is held by static friction until
the gravity component along the surface exceeds the maximum
static friction force:

```
m·g·sin(θ_s) > μ_s · m·g·cos(θ_s)
→ tan(θ_s) > μ_s
```

For foam-on-vinyl on this platform, `μ_s ≈ 0.07`, so `θ_s ≈ 4°`.
Below 4° tilt, the ball will not move regardless of how long the
tilt is applied.

**Diagnostic**: STEP_ID's "Stiction characterisation" phase
(2026-05-01, commit `1d49f1d`) measures this directly. Ramp tilt
from 0° at 0.5°/s, watch for first ball motion, record IMU-actual
tilt at motion onset.

**Where it matters**:
- The PID's `commanded tilt = Kp · err`. If `Kp · err < θ_s`, ball
  doesn't move. Either the integrator slowly winds up to break
  through (overshoot, limit cycle), or the stiction-relief PID
  branch (commit `2eb6235`) boosts to `max_tilt` after
  `stiction_break_s` of stuck-ball detection.
- Open-loop plant-ID tilt magnitude must be > `θ_s + 1°` or the
  ball won't move during the trial → fit produces near-zero G_eff.
- Closed-loop `max_tilt_deg` floor must be `θ_s + 2.5°` minimum,
  otherwise the recommended Kp at small errors produces tilts
  below stiction breakthrough → stuck ball.

### Orbital braking (`θ_orb`)

A ball moving in a circular orbit at tangential velocity `v` and
radius `r` experiences centripetal acceleration `v²/r`. To brake
it via gravity-along-surface:

```
g·sin(θ_orb) > v² / r
→ sin(θ_orb) > v² / (r · g)
```

For a ball at rim (`r = 200 mm`) at `v = 500 mm/s`:
`sin(θ_orb) > 250000 / (200 · 9810) = 0.127` → `θ_orb > 7.3°`.

This depends on the ball's *instantaneous* state. A faster ball
needs more tilt; a ball not in orbit needs none.

**Where it matters**:
- If `max_tilt_deg < θ_orb` for the orbit the controller has
  driven the ball into, you are physically incapable of braking
  it. Symptom: orbital limit cycle that persists indefinitely
  regardless of gains.
- Recommended floor: `max_tilt_deg ≥ 8°` to handle up to
  `v ≈ 530 mm/s` orbital velocity. Combined with stiction floor:
  `max_tilt_deg = max(θ_s + 2.5, 8.0)`.

### These two are NOT the same number

Stiction characterisation gives `θ_s` only. It tells you nothing
about `θ_orb`. Don't conflate them. If your stiction phase says
`θ_s = 3°` and you set `max_tilt = 5.5°`, the ball can break
stiction fine but cannot recover from a moderate orbit.

---

## Plant ID methodology — what we tried, what stuck

We went through three generations of G_eff fitting in one evening.

### Gen 1: parabolic position fit on a fixed window (initial design)

Fit `x(t) = c0 + c1·t + ½·a·t²` over `[ramp_end, end_of_tilt]`.
G_eff = a / θ_commanded.

**Failure mode**: when stiction holds the ball through most of
the tilt window, the fit captures a near-flat trajectory and
returns `G_eff ≈ 0`. The ball moves *after* the fit window — too
late.

### Gen 2: parabolic + peak-velocity fallback

Added `_fit_velocity_based_g_eff` = `peak_v / ∫|θ_imu(τ)| dτ` over
`[0, peak_v_t]`. Use this when parabolic returns implausibly low.

**Failure modes**:
- `np.max(v_along)` picks up vision-glitch frames (peak_v = 2505
  in one session, 5500 in another — physically impossible).
- `peak_v_t` happens at variable times relative to the tilt-phase
  boundary, so `integrated_tilt` covers different windows
  → variable G_eff.

Mitigations applied: 95th-percentile instead of np.max; multi-
frame consensus for the safety cutoff. Improved consistency from
51% → 40% CV but still not enough.

### Gen 3 (current): linear regression v(t) vs ∫θ(τ)dτ

The physics: `a = G·θ` integrates to `v = G·∫θ + C`. The slope of
`v(t)` plotted against `∫θ(τ)dτ` IS the plant gain.

```python
# 1. Median-filter ball position (kernel=5) — eats single-frame
#    V0 dropouts.
xs = _median_filter(xs_raw, 5)
ys = _median_filter(ys_raw, 5)
# 2. Velocity from smoothed position (central differences).
vx = np.gradient(xs, ts); vy = np.gradient(ys, ts)
v_along = vx · ax_dir + vy · ay_dir
# 3. Cumulative integral of |IMU tilt| from t=0.
cum_int_tilt = trapezoidal_integral(|imu_dominant|, ts)
# 4. Detect motion onset = first t where smoothed v > 30 mm/s
#    for ≥3 consecutive frames.
# 5. Linear regression v(t) vs cum_int_tilt(t) over
#    [motion_onset, end_of_samples]. slope = G_eff.
# 6. Drop residuals > 3σ, refit once.
```

**Why this is more robust**:
- All samples in motion window contribute (least-squares),
  not one extremum.
- Vision-glitch outlier residuals get dropped at 3σ.
- Cumulative integral handles non-constant tilt naturally
  (post-tilt-end ramp-down doesn't bias the slope).

**Status** (2026-05-01 evening): not enough sessions to fully
characterise, but appears to give significantly tighter CV than
peak-velocity. Still subject to fundamental vision-noise limits.

---

## Vision noise — the underlying constraint

Across all three generations of plant-ID and across both Demo 2
verification trials, vision noise was the dominant source of
trial-to-trial variation. Some specific manifestations:

- **Peak velocity 4500–5500 mm/s in verification trials** with a
  ball that physically tops out around 800. These were single-
  frame V0 false-positives where the detector locked onto a
  shadow / glare / hand briefly.
- **Trajectory looks "flat then jumps"** in the open-loop ball
  position record. V0 lost the ball during fast motion (the V0
  HSV failure mode documented in `vision_control_tuning_lessons.md`)
  and re-acquired at a new position 50+ mm later.
- **`/oak/health.v0_arr_hz`** typically 25–28 Hz across these
  sessions — 30 Hz target met. Detection *rate* is fine; it's
  detection *accuracy under motion blur* that fails.

**Mitigations applied (controller-side)**:
- Velocity sanity gate (`BT_MAX_BALL_VEL_MM_S = 800`) caps the
  velocity used by Kd. Removes the dominant energy-injection
  mechanism. Active by default.

**Mitigations applied (digest-side)**:
- Median-filter on ball position before velocity calculation in
  open-loop fit.
- 95th percentile instead of np.max for peak velocity.
- Linear regression with 3σ outlier rejection.

**What we did NOT try (but probably should before next attempt)**:
- Tuning the KF measurement noise R higher to dampen vision
  spikes at the source.
- Hampel-filter on /ball_state position with a 5-frame window.
- Switching V0 backend to "depth blob" (the parallel detector
  documented in `vision_control_tuning_lessons.md` — if it ever
  works on this surface).
- Increasing rgb_fps to 90 if the OAK supports it (more samples
  per dt → smaller per-frame outlier impact on velocity).

---

## Architectural changes shipped

In rough order of impact:

### Cascade-bypass for BALL_TRACK (commit `b9dee51`)

`_start_ball_track_loop` now stops the level-PI loop on entry and
re-enables it on exit (only if it was on before). BALL_TRACK
commands tilts directly via `_do_set_pose` / IK with no inner-loop
transient. Reverses the architectural decision in `controls_journey.md`
lesson #6 ("closing the inner tilt loop on IMU is essential").

**Tradeoff**: plant biases (leg backlash, IK approximations,
gravity sag) used to be absorbed by level-PI's IMU feedback. Now
they show up as ball-position bias which the outer integrator
must compensate over time. Slower bias rejection in exchange for
much faster transient response.

### Velocity sanity gate in PID (commit `f542b64`)

Cap `|edot|` at 800 mm/s before applying Kd in `_ball_track_run`.
Removes vision-noise-driven Kd saturation events. Single biggest
fix for the orbital limit cycle problem.

### Stiction relief in PID (commit `2eb6235`)

Borrows the bang-bang STICTION_BREAK pattern. When `vel_mag <
stiction_v_threshold AND err_mag > err_tol AND held > stiction_break_s`,
the PID's commanded tilt is scaled up to `max_tilt` while
preserving direction. Phase reports `STICTION_BREAK` (code 4).
Targets the "Kp·err < θ_s, ball stuck, integrator winds, eventual
overshoot" failure mode.

### PID latency lookahead (commit `a1fbfdb`)

`ex_lead = ex + edot_x · control_latency_s`. The PID's P term
reacts to where the ball will be when our tilt command actually
takes effect (~100 ms ahead), not where it was. Mathematically
equivalent to bumping Kd by `Kp·Td` — keeps the analytic
recommendations' predicted closed-loop poles intact in the
presence of cascade dead-time.

### Multi-frame consensus safety cutoff (commit `49fb700`)

The open-loop trial's safety cutoff (end tilt early if ball
exceeds velocity limit) used single-frame velocity, which
vision-noise spikes (1234 mm/s in one trial) tripped
inconsistently. Now requires 3 of last 5 samples over the limit
before cutting. Limit raised from 350 to 1500 mm/s — foam ring
handles real escape cases.

### Z-compensation cleanup on ball_track exit (commit `f91f49c`)

`_ball_track_run` does `z_cmd = z_hold + px·sin(pitch) − py·sin(roll)`
per tick to rotate platform UNDER the ball. Last tick before exit
left the platform at `z_hold ± ~10 mm` displacement. Level loop
then tracked that displaced pose forever — operator observed the
"~10 mm Z dip after every Demo 2 run" symptom.

Fix at loop exit: send `_do_set_pose(0, 0, z_hold, 0, 0, 0)`.
Whatever picks up after BALL_TRACK starts from a known clean
state.

---

## STEP_ID phase-by-phase: when to run what

The 2026-05-01 split into per-phase Run buttons (commit `1d49f1d`)
gives you these independently-runnable phases:

### 1. Stiction characterisation (`/step_id/run_stiction`)

**Run when**: starting a new tuning session on this hardware,
after physical changes (clean ball, replace platform surface,
new lighting), or to diagnose "ball doesn't break loose"
behaviour.

**Outputs**: `θ_s` (breakaway tilt), `μ_s` (friction coef),
recommended `max_tilt_deg ≥ θ_s + 2.5°`, recommended open-loop
tilt magnitude `≥ θ_s + 1°`.

**Time**: ~10–25 s wall-clock (ramp at 0.5°/s up to 8° max).

### 2. Open-loop plant ID (`/step_id/run_open_loop`)

**Run when**: stiction known, want analytic Kp/Kd recommendation.
Set the open-loop tilt magnitude in the GUI to `θ_s + 1°` first.

**Outputs**: G_eff (mean ± std across n replicates), recommended
Kp/Kd/Ki/max_tilt_deg in `step_id_recommendation.json`. Refuses
to recommend if CV > 0.30 across n≥2 replicates.

**Time**: ~3 minutes for n=3 default.

### 3. Closed-loop verification (`/step_id/run_verification`)

**Run when**: gains have been applied, want to see whether they
actually settle the ball before shipping. The 4-trial protocol
exercises both 92 mm and 170 mm step distances.

**Outputs**: per-trial settled/not, `verification_summary` in
`step_id_recommendation.json`, post-hoc `refined_gains` suggestion
if the trials reveal failure patterns (orbital, undershoot,
saturation, vision-noise jitter).

**Time**: ~3–6 minutes (each trial 25 s timeout + 3 s settle +
operator placement time).

### Full session (`/step_id/start`)

Runs all three in sequence. Use when starting completely fresh.

---

## What we tried that didn't work

- **YOLO v8 vs cv2 HSV.** Operator A/B test showed v8 had ~20%
  better detection accuracy on stationary balls under controlled
  lighting, but during actual demos v8 lost the ball almost
  immediately. Reverted boot default to cv2 HSV. v8 still
  available via runtime backend selector.
- **`OAK_FORCE_V1_ARCH=v8` then back to cv2.** Briefly committed
  to enable v8 by default; reverted within 30 minutes when v8
  proved worse for our specific motion profile.
- **Aggressive `Kp = 0.077`** from one analytic recommendation
  (G_eff=224 from a single replicate). Saturated max_tilt = 2.5°
  at any error > 32 mm. Drove the ball into orbital limit cycle
  every trial. Lesson: high Kp without high max_tilt is just
  bang-bang in disguise.
- **`OAK_FORCE_V1_ARCH=v8` with the existing recommendation.**
  Wanted to compare clean v8 trials against cv2 trials. Couldn't
  complete a single open-loop trial with v8 — vision lost ball
  every time.

---

## Open questions / what we never characterised

These would be worth doing on a future tuning round:

1. **Direct measurement of `θ_orb` / orbital velocity.** We have
   `θ_s` from the stiction phase. We never directly measured the
   orbital velocity that develops on this platform with the
   current vision noise + gain regime. Could add a 4th STEP_ID
   phase: drive ball into a known orbit at known tilt, observe
   steady-state orbital v, compute required braking tilt.
2. **KF measurement noise tuning.** We never adjusted the Kalman
   filter's R parameter to match measured vision noise variance.
   Would dampen velocity spikes at the source rather than at
   the controller's input.
3. **Inner-loop level-PI bandwidth measurement.** We disabled
   level-PI for BALL_TRACK because it was too slow; we never
   characterised exactly how slow. A short tilt-step trial with
   no ball + IMU recording would give us a 2nd-order fit on the
   inner loop.
4. **Vision exposure/gain trade-off under motion.** `controls_journey.md`
   covered exposure tuning for stationary detection. We didn't
   re-tune for motion — shorter exposure + brighter lighting +
   higher ISO might cut motion blur at the cost of noise.
5. **Detection rate vs control rate budget.** /oak/health shows
   `v0_arr_hz ≈ 27`, `v0_pub_hz ≈ 12.5`. The publish rate is
   capped somewhere; if we could get publish to match arrival
   we'd halve the effective vision latency.
6. **Plant gain at different Z heights.** All STEP_ID runs were
   at start_z = 80 mm. Foam ball normal force vs friction
   coefficient may vary with Z; closed-loop demos at the
   specified Z = 30–50 mm range may have different G_eff.

---

## Where the system stands as of 2026-05-01 evening

- ✓ Vision: cv2 HSV @ 27 Hz arrival, 12 Hz publish. v1_yolo
  available but worse for fast motion on this hardware.
- ✓ Cascade architecture: BALL_TRACK bypasses level-PI, commands
  tilts directly via IK.
- ✓ PID stiction relief active (boost to max_tilt when stuck).
- ✓ PID latency lookahead active (~100 ms phase compensation).
- ✓ Velocity sanity gate (Kd input capped at 800 mm/s).
- ✓ STEP_ID per-phase Run buttons in GUI.
- ✓ Stiction characterisation phase implemented and ready to use.
- ✓ Z-compensation cleanup on BALL_TRACK exit (no more 10 mm dip).
- ⚠ Demo 2 closed-loop tracking still showing orbital limit cycles
  in some configurations. Believed addressable with `max_tilt =
  max(θ_s + 2.5, 8)` + appropriate Kp/Kd combination — operator
  iteration in progress as of doc-write time.
- ⊘ Plant ID still produces 30–50% CV across replicates on this
  hardware. Vision noise is the bottleneck.

The Demo 2 tuning is operator-driven from here — typing values
into the Gains & Control Parameters panel, running Demo 2,
reading the next-step banner from the digest, iterating. The
infrastructure is in place; the limit is now physical (vision
noise, stiction variability) rather than software.

Onward.

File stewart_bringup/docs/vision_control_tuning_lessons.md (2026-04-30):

# Stable-Bot Vision + Control Tuning — Session Writeup (2026-04-30)

## What we set out to do

Bring up the three closed-loop ball demos (orbit, click-to-goto,
path-drawing) on the Pi-side Stewart platform. The vision stack was
nominally working; control loops weren't, and vision had reliability
issues we discovered along the way. By the end of the session the
vision pipeline is reliable, the controller architecture is correct,
and we have the diagnostic infrastructure to tune the demos
systematically rather than by guess-and-check.

---

## Architectural changes (what's different now)

### Vision pipeline

**Two parallel ball detectors instead of one.** V0 (HSV color
threshold inside the platform-mask region) and depth-blob
(above-platform-plane stereo blob inside the same mask). Both publish
independent pixel topics; ball_localizer projects both into
platform-frame mm and publishes `/ball_xy_mono` and `/ball_xy_depth`.
The GUI shows them as orange and cyan circles for direct comparison.

**Stereo close-range fix via ExtendedDisparity.** Default OAK stereo
cuts off at ~632 mm; the platform sits at ~600 mm. Setting
`setExtendedDisparity(True)` doubles the disparity range and halves
the minimum measurable distance to ~316 mm — the entire platform now
sits comfortably inside the stereo envelope.

**Self-calibrating depth-blob plane fit (then removed).** First
attempt computed `median(expected − measured)` across the eroded mask
as a per-frame plane offset; with smooth-surface stereo dropouts, the
median was driven by stereo edge artifacts at 1.5 m and the threshold
drifted. Removed in favor of trusting the ArUco-derived plane
directly with the threshold on raw `expected − measured`.

**ArUco→IMU alignment baked into ball_localizer.** The IVA sweep's
Procrustes fit measures a constant 2D rotation between ArUco-derived
camera RPY and IMU body RPY — this platform shows a 149-156° rotation
that no `±1` sign flip can compensate. The digest now writes a
standalone `aruco_imu_alignment.yaml`, and ball_localizer applies it
to ball xy in platform frame. Result: BALL_TRACK loop sees
IMU-aligned coordinates regardless of how the ArUco markers happen to
be oriented relative to the IMU body frame.

**Vision lag eliminated.** Three compounding bottlenecks:

- rosbridge JSON-array bloat (200 KB JPEG → 1.4 MB wire payload).
  Mitigated by `throttle_rate=100`, `queue_length=1`, and dropping
  OAK MJPEG quality from 95 to 70.
- Browser-side `String.fromCharCode + btoa` loop per frame
  (200K-iteration JS hot path). Replaced with
  `URL.createObjectURL(Blob)`, ~150x faster.
- `/oak/depth_blob/debug_image` overlay broadcast for visual
  diagnostics (annotated RGB with mask outlines + above-plane tint +
  detection circle).

### Controller

**Concurrent BALL_TRACK + level PI loop.** Previously these were
mutually exclusive: starting BALL_TRACK explicitly stopped the level
loop, leaving the controller open-loop on platform tilt. The fix
removes the mutual exclusion and auto-enables level when BALL_TRACK
starts. Now BALL_TRACK writes `current_rpy` as a desired-tilt
setpoint; the level loop's existing `target = level_ref + current_rpy`
formula treats it as a setpoint and uses IMU feedback to actually
achieve the commanded tilt. **IMU is the ground truth for platform
tilt**, no longer "commanded == actual" assumption.

**Bang-bang algorithm alternative to PID.** Selectable via
`algorithm: 'pid' | 'bangbang'` in `ball_track_gains.yaml`. Bang-bang
implements an explicit state machine: ACCELERATE (full tilt toward
target) → COAST (zero tilt while ball coasts) → BRAKE (full opposite
tilt) → SETTLE (zero tilt within tolerance). State machine is more
interpretable than continuous PID; each threshold has physical
meaning instead of being an interaction-laden gain.

**Bang-bang stiction breakthrough.** Foam-on-vinyl static friction
often pins the ball at `accel_tilt=3°`. New STICTION_BREAK phase: in
ACCEL with velocity below `stiction_v_threshold_mm_s` for more than
`stiction_break_s`, ramp tilt to `max_tilt_deg` (typically 6°) to
break the ball loose. Reverts to ACCEL once the ball moves.

**Asymmetric brake_tilt_deg.** Static friction (overcome at startup)
is much higher than kinetic friction (rolling ball). A fast-moving
ball needs *more* tilt to brake than a stationary ball needed to
start, because kinetic-friction-limited deceleration is
`g·sin(θ)·α`. Now `accel_tilt_deg` and `brake_tilt_deg` are
independent.

**Vision-latency lookahead.** End-to-end vision-to-command latency is
~100 ms (capture, USB transfer, KF processing, control loop). At
300 mm/s ball speed, this is 30+ mm of position drift; BRAKE phase
fires after the ball has already overshot the brake horizon. Now the
FSM extrapolates `(px, py)` forward by `control_latency_s` using KF
velocity before computing phase decisions.

**Z-compensation for off-center rotation.** Without compensation, a
tilt by θ with the ball at offset px adds `px·sin(θ)` of heave to the
ball's world-frame height. Now the BALL_TRACK loop commands
`z_cmd = z_hold + px·sin(pitch) − py·sin(roll)` so the platform
rotates *under* the ball — ball's world height invariant, only
surface gradient changes.

**Ball-fall plumbing fixed at three layers.** ball_localizer drops V0
cache after 0.4 s (no more 60 Hz publishing of stale-V0 positions).
ball_kf only publishes `/ball_state` when measurements are fresh
(predict still runs, but no broadcast on extrapolation). GUI hides
the SVG ball after 0.8 s of `/ball_state` silence and clears the
trail.

---

## Diagnostic infrastructure built

These are the workhorses for tuning. Each one mirrored an existing
pattern (the IVA bag pipeline) so the UX is consistent.

### Bag pipelines

**Vision-debug bags.** `/vision/start`, `/vision/stop`, list, digest,
push. Records RGB, depth_blob debug overlay, V0/depth pixel +
diagnostic, platform_pose, IMU. Digest extracts up to 9 keyframes
from the debug overlay and produces multi-panel plots (detection
rate, plane offset, mask occupancy, fail-reason breakdown). Push
commits **only** the digest artifacts; raw mcap stays on the Pi
(gitignored).

**Demo-run bags.** `/demo/start` with label dropdown
(`demo1` / `demo2` / `demo3`). Records ball state, ref, IMU,
control_cmd/result, status, leg encoders/currents, and the new
`/ball_track/diagnostic` topic (per-tick FSM phase + commanded
tilts). Digest produces a 7-row plot: 2D trajectory + error magnitude
+ x/y tracking + KF velocity + IMU tilt + leg currents + **phase
strip** (color-coded scatter showing which FSM phase the controller
was in at each tick, with commanded tilts overlaid).

### GUI panels

- **Gains & Control Parameters** (Demos column): live-editable PID
  gains + bang-bang thresholds + algorithm dropdown. Mirrors
  Level-PI Tuning panel exactly. Save writes to YAML and reloads
  in-memory; no service restart.
- **Demo Run Bag Recording**: same UX as IVA / vision-debug. Per-bag
  inline summary stats + digest/push/PNG/delete.
- **Vision Debug detector toggle**: V0 / depth-blob / both, with live
  readouts for each detector's ball position in mm.

### Telemetry

- `/ball_track/diagnostic` (Float32MultiArray, 11 fields) — FSM
  phase, commanded tilts, error/velocity/unit-error vector. Bagged
  by demo recorder. **Color-coded phase strip** in the digest is what
  makes bang-bang tuneable.
- `/oak/ball/depth/diagnostic` (Float32MultiArray, 22 fields) — algo
  internals + frame-wide depth distribution + probe-style pose vs
  measured. Lets the digest answer "why didn't depth-blob detect?"
  without raw images.
- `[health]` log lines from oak_driver + ball_localizer (5 s cadence)
  — pose count, V0/depth detection rates, mask state, intrinsics
  state, gate accept/reject counts.

### Pose persistence

`~/.stewart_control_state.json` saves last-commanded
`(current_xyz, current_rpy)` on every mutation. GUI Z sliders read
from `/status` on connect, so they show the last setpoint instead of
`0` after a service restart.

---

## Specific bugs found and fixed

A non-exhaustive list of the more painful ones, in roughly
chronological order:

- **OAK USB power browned out the Pi 5** — solved with a separate
  wall charger via splitter into the Spotpear hub.
- **OAK depth aligned to CAM_A required `setLeftRightCheck(True)`** —
  pipeline halted at error 180 otherwise.
- **IR projector contaminating mono cameras broke ArUco corner
  detection** — moved ArUco to RGB stream (memory
  `feedback_oak_ir_vs_aruco`).
- **stereoRectify K diverged from DepthAI's internal K by 13.58 px**
  — solved by publishing raw mono left + raw factory K + all 14
  distortion coefficients (rational model).
- **stewart_control_node startup deadlock** —
  `_open_bus_and_start_threads` held bus_lock then called read_sdo
  which acquired the same lock. Fix: release lock before SDO reads.
- **CBOR-raw broke the GUI entirely** — rosbridge on Pi/Kilted didn't
  honor it, zero frames arrived. Reverted; kept Blob URL +
  JPEG-quality drop.
- **Double-const SyntaxError** — added `const now = performance.now()`
  for a diagnostic log when the same name was already declared lower
  in the same function. JS refuses to parse the entire script,
  killing the rosbridge connection.
- **Save-hang on gains panel** — `ball_track_save_gains` reply
  handler nested inside `if (r.cmd.startsWith('level_'))` gate.
  Pulled out into a sibling block.
- **Demo 2 auto-targeted center on Start** — the bolt at center made
  this dangerous. Fixed: `_compute_ref` returns None when
  `x_mm`/`y_mm` not in params; ball-fall recovery exempts ref-stale
  (only counts state-stale).
- **Phantom-ball propagation through three caching layers** —
  ball_localizer cached V0 forever, KF predicted forever, GUI showed
  the dot forever. Fixed at all three layers with freshness gates.

---

## Lessons learned (the hard-won ones)

These are insights that would have saved hours had we known them up
front:

1. **Frame mismatches are silent.** When the ArUco board's frame is
   rotated relative to the IMU body frame, no combination of
   `pitch_sign / roll_sign` can compensate. The signs only mirror,
   not rotate. The Procrustes fit from an IVA sweep is the only way
   to know — a small `det=±1` and a `rotation_deg` near a multiple of
   90° is the smoking gun.

2. **Stereo on smooth surfaces fails predictably.** Carbon fiber +
   vinyl + foam ball + IR projector = "stereo gives correct depth at
   marker edges but invalid (or wrong-matched to background) on the
   platform interior." The pattern manifests as 80%+ "valid" pixels
   in the mask but a median height pegged at the wrong sign. The fix
   is either to add texture or to abandon stereo for the
   platform-tracking task.

3. **Camera close-range limits aren't documented prominently.** The
   OAK's default stereo cutoff of ~632 mm cost us multiple bags
   before we noticed `depth_min=632` constant — a giveaway that the
   platform was below the close-range limit. `ExtendedDisparity`
   doubles the range, costs only a small compute increase.

4. **Vision-to-command latency dominates fast control.** ~100 ms from
   photon to motor is enough to BRAKE 30 mm late at 300 mm/s ball
   speed. Lookahead by `velocity × latency` is a simple, big-win
   compensation. The user's instinct that "the platform can't
   compensate fast enough" was correct — the fix is computing phase
   decisions on the lead-extrapolated position.

5. **Static vs kinetic friction asymmetry matters.** A foam ball at
   rest on vinyl needs more tilt to start moving than the same ball
   moving at 500 mm/s needs to brake — but only because the ball at
   rest is *immobile* below the static-friction tilt threshold. Once
   moving, kinetic friction is much lower. This means ACCEL needs
   *high* tilt to break stiction, while BRAKE on a fast-rolling ball
   *also* needs high tilt to overcome the ball's kinetic energy.
   Symmetric bang-bang ignores this asymmetry; separating
   `accel_tilt_deg` from `brake_tilt_deg` (with stiction breakthrough
   as a third level) captures the actual physics.

6. **Closing the inner tilt loop on IMU is essential.** Without it,
   BALL_TRACK is open-loop on platform tilt — commanded tilt and
   actual tilt diverge by static plant bias (asymmetric leg backlash,
   gravity sag, IK approximations). The ball drifts to the corner
   where commanded == actual − bias, and the controller can't escape
   because it doesn't know about the bias.

7. **Phase telemetry is mandatory for FSM debugging.** Without
   `/ball_track/diagnostic`, "stuck in ACCEL forever (stiction)" and
   "rapidly chattering ACCEL↔COAST↔BRAKE (thresholds wrong)" both
   look like "ball doesn't track" in the bag. The phase strip
   distinguishes them in one glance.

8. **Bag-driven tuning beats guess-and-check.** Live-editable gains
   via the GUI + auto-recorded demo bags + auto-digest produces a
   tuning timeline in `git log`. Every gain change becomes a diff,
   every run becomes a digest commit. Far more disciplined than
   tweaking gains and watching by eye.

9. **rosbridge image streaming is bandwidth-heavy.** JSON-array
   serialization of `uint8[]` data inflates 7×; JPEG decoding via
   `String.fromCharCode + btoa` blocks the JS event loop. Both
   compound. Fixes: lower JPEG quality at the publisher, throttle at
   the bridge, Blob URLs at the browser.

10. **The ball-on-plate problem is fundamentally 2D + planar-
    constraint.** Solving it via 3D depth perception is overkill (and
    brittle on smooth surfaces). V0 (color) + ArUco (plane) +
    ray-plane intersection gives sub-mm position with a single
    camera. The depth-blob detector is a research artifact, not a
    production necessity.

---

## What's still open

- **Demo 1 (orbit) tuning** with the new infrastructure — pending
  another round with the alignment, latency lookahead, brake_tilt,
  and z-compensation all live.
- **Demo 3 (path) ref_generator** — `BALL_TRACK_PATH` is still
  stubbed, returns the first waypoint only. Arc-length traversal at
  speed (with the same closest-waypoint snap as Demo 1) is a
  self-contained ~30-line implementation.
- **End-to-end latency measurement** — a "ball-tap" digest analyzer
  that times from V0 detection to motor response. Enables tuning
  `control_latency_s` empirically instead of using the 100 ms
  estimate.
- **Stereo on the deck (research)** — whether adding fine-pitched
  texture (printed dot pattern) makes depth-blob useful. Not
  currently a priority.

---

This represents about a day's worth of architecture changes plus a
roughly equivalent amount of bug investigation. The diagnostic
infrastructure (bag pipelines + phase telemetry + alignment auto-cal)
is the most durable contribution — the controller-side knobs (PID vs
bang-bang, brake_tilt, z_comp) are tuneable in 5-10 bags now that we
know what we're looking at.

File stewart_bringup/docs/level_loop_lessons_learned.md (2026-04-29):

# Level-loop tuning saga — lessons learned

Compiled at end of the 2026-04-27 → 2026-04-29 controls journey, from
the iter-1 baseline (a5b717d, RMS 0.12°) through the wL_FF=False
regression that took us 30× backward, the firmware harmonization,
the empirical-Jacobian system-ID, to the final sub-0.1° steady-state
hold.

The lessons aren't ordered by importance — they're ordered by the
pattern of mistakes that each lesson prevents future-you from making.

---

## 1. Distinguish "runtime" from "persistent" state on every CAN write

**The single recurring bug all month.** ODrive's CAN protocol has two
paths for changing parameters:

| mechanism | scope |
|---|---|
| Standard CAN cmd 0x00B (`Set_Controller_Mode`), 0x00F (`Set_Limits`) | runtime only — reverts on disarm/reboot |
| SDO write to a config endpoint (e.g. id=315 `current_soft_max`) | runtime only too |
| `save_configuration()` (id=710) | persists current runtime to flash |
| Per-drive default values from cal / DFU | overwrite persistent state |

We hit the same class of bug at least four times:

- The GUI's "set leg current" slider sent `Set_Limits` (runtime), so
  any disarm or reboot reverted to the 6 A flash default. Fixed in
  e1c1c8d by also syncing `self.leg_current_a` from flash on bus open.
- `wL_FF_enable` got reset to False by the configurator, persisted to
  flash, and the next 5 sweeps regressed by 30×. Fixed by rolling
  back the default and adding a runtime self-heal in
  `_prepare_for_level`.
- `control_mode` got reset to VELOCITY (=2) by WebGUI's "Run
  Configuration Script" multiple times. Same pattern: WebGUI persists
  factory defaults, our runtime tries to use POSITION, watchdog
  disarms.
- `current_soft_max` reverted to 6 A whenever recalibration ran. Same
  pattern.

**Rule going forward:** every parameter the level loop depends on
must be (a) written persistently to flash via the configurator AND
(b) re-asserted at runtime via `_prepare_for_level` on every level-on.
Neither alone is enough. The runtime write is the safety net; the
flash write is the fast-boot path.

---

## 2. The IK was wrong — by 100-450%

This was the load-bearing discovery. The geometric IK in
`_compute_motor_targets` produces leg-length deltas assuming a
perfectly-built platform with idealized geometry. Reality has:

- Per-leg sign convention errors
- Asymmetric mounting angles
- Per-leg gain mismatch from belt tension / pulley alignment
- Z-dependent nonlinearity from leg-extension geometry

The empirical Jacobian measured on 2026-04-29 (system-ID run at 5 Z
heights × 4 δ values × 6 legs × 3 reps) showed the geometric IK had
**wrong signs on multiple legs** for the roll axis. Theoretical said
"leg 1 increases roll +7.2 °/turn," reality said "leg 1 barely affects
roll, −0.3 °/turn." Mean magnitude error was 130% on roll, 450% on
pitch.

**Bag-level effect**: with the geometric IK the level loop reached
RMS 0.218° at best. With the empirical Jacobian (commit 275ea77),
same gains, **RMS dropped to 0.110° on both axes** — and the
integrator drift went from 1° peak-to-peak (chasing the IK
mismatch) to 0.05° (loop sitting steady). 27× tighter steady-state
deviation, 19× less integrator wind-up.

**Rule going forward:** any time the loop fights a "systematic
offset" the integrator can't quite close, suspect the IK before
suspecting gains. Tuning gains on top of a broken model is wasted
effort.

---

## 3. "Tune the gains" is the WRONG default debugging instinct

When tracking degraded, the natural reflex was "lower KP" or "add
deadband" or "tune integrator decay." Sometimes those helped. More
often they masked a different root cause:

- Sweep on 2026-04-28 22:22 (post-wL_FF-regression-recovery): tuning
  felt limited by something. Was actually the inner-loop feedforward
  being off. No outer-gain tweak fixed it; only the wL_FF restore did.
- 2026-04-29 03:02 sticky-then-release: looked like classic stick-slip
  needing higher current. Was actually the IK gain mismatch — the
  loop was over-correcting because corr→tilt response wasn't 1:1.
- 2026-04-29 05:18 to 05:26 jacobian-vs-geometric A/B: same gains,
  swap IK only, **2× tighter RMS**. Tuning never could have produced
  this.

**Rule going forward:** before tuning gains, verify (1) inner-loop
state via `inner_loop_config` snapshot in the bag, (2) IK fidelity
via empirical Jacobian. If those are wrong, tune nothing — fix them.

---

## 4. Diagnostic infrastructure pays for itself within 2 bags

We added diagnostic features in this order, each prompted by a
specific frustration:

1. **`/level_diag` topic** with per-tick state, errors, integrator,
   correction. Made the loop's behavior visible at 50/200 Hz.
2. **`per_leg_state` + `active_errors` + `feeder_mode` + `yaw`** in
   LevelDiag. Caught the 1° rms regression as "platform actually
   running but at a 12° tilt the loop can't correct" instead of "
   loop is broken."
3. **`inner_loop_config` snapshot** at bag start, per Z. Caught the
   wL_FF=False regression in 5 minutes by diff'ing snapshots, when it
   would otherwise have taken hours of bisecting commits.
4. **Diagnostic plot grid** (6 panels per bag) and overview plot per
   sweep. Visual, not numerical, often surfaces the smoking gun
   faster — e.g., the integrator-drift panel showed obvious wind-up
   patterns that the JSON stats hid.
5. **`compare_bags.py`** for side-by-side digest tables across runs.
   The Jacobian-vs-geometric comparison was a 2-line invocation.
6. **System-ID** for the empirical Jacobian itself.

Every one of these was high-leverage AFTER it was built. Time spent
building diagnostics paid back many times over in time saved
debugging.

**Rule going forward:** when iterating on a control system, build
the next diagnostic the moment "I wish I could see X" comes up. Don't
delay-and-debug; build-first-and-debug.

---

## 5. Sticky-flash, runtime self-heal, and bag-start snapshots are the right pattern

The combination ended up being:

- **`set_odrive_feedforward_via_can.py --apply`** with the right flags
  → sets persistent flash values via SDO + `save_configuration()`
- **`_prepare_for_level()`** at every level-on → runtime SDO writes
  for `control_mode`, `input_mode`, `wL_FF_enable`, plus seeds feeder
  pos targets from current encoders
- **`_lr_capture_inner_loop_config()`** at bag-start → SDO snapshot
  of every relevant runtime config field, dumped to the sidecar
- **Analyzer's `inner_loop_config` block in summary.json** with
  `any_differ_across_drives` flag → asymmetry between drives jumps
  out instantly

This 4-layer pattern survives any one layer's failure. Future
parameters added to the level loop should go through all 4: persist
via configurator, self-heal in `_prepare_for_level`, snapshot at
bag-start, surface in the analyzer.

---

## 6. Run-once empirical models beat per-tick computation

Replacing `_compute_motor_targets`'s rotational IK with the empirical
Jacobian's pseudo-inverse:

- Adds ~5 ms of compute at node startup (load JSON, pinv 5 matrices)
- Removes per-tick trig from the geometric IK, replaces with one
  6×3 × 3×1 matrix-vector multiply (~50 ops)
- **Net: cheaper per tick than the original geometric IK**

The pattern generalizes: any time a per-tick computation depends on
quantities that don't change with state (geometry, calibration), it
should be precomputed at startup and looked up at runtime.

---

## 7. Don't recompute the bag-comparison spreadsheet by hand again

Manual comparison was ~80% of the friction. `compare_bags.py` does
in 5 seconds what was taking 20 minutes of cross-referencing JSON
files. Build it once, use it dozens of times.

The JSON output of every bag is structured for diff'ing on purpose:
nested `gains` block, nested `inner_loop_config`, nested `health`,
nested `settling`. Future analysis tools should rely on this
structure rather than custom regex'ing CSV columns.

---

## 8. The platform's Jacobian is a property of the robot, not a
control gain

This was the surprising-in-retrospect insight. Once we measured the
empirical Jacobian, it became clear: this isn't a knob we tune. It's
a measured property of the build. Run the system-ID once, save the
JSON, the IK is correct forever (until you change the mechanism).

That moves the level-loop tuning from "fight a moving target" to
"hold a known steady model" — which is why the same gains that gave
RMS 0.4° with geometric IK gave RMS 0.11° with empirical IK.

---

## 9. Specific bugs to never reintroduce

- **Don't use `current=6.0` as the arm-flow default.** Always use
  `self.leg_current_a` (the slider value) which is in turn synced
  from flash on bus open.
- **Don't write CMD_SET_LIMITS without also surfacing what was
  written in the GUI.** Runtime writes that aren't visible cause
  "phantom" parameter values.
- **Don't run a sweep with step_amp = 1° on a platform with 6 A
  current limit.** It can stall a leg against an endstop.
- **Don't trust the WebGUI's "Run Configuration Script" to leave
  `control_mode` and `input_mode` alone.** It sets them to factory
  defaults and persists. Always re-run the configurator after any
  WebGUI session.
- **Don't analyze a bag without checking the `inner_loop_config`
  asymmetry warning.** It's the smoking gun for any per-drive
  miscalibration.

---

## 10. Net score

Started: RMS ~5.4° / RMS ~12.1° (the "fucked error" run, post-
regression baseline before recovery).

Ended: RMS 0.110° on both axes, ss_std 0.015°/0.042°, **94% of the
bag inside ±0.20°, 46% inside ±0.10°.** Settles in 2-5 seconds.

100× tighter than where we started, fully repeatable, and the IK
is now a measured property of the robot rather than a guess.

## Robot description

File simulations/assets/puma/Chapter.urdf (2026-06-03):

<?xml version='1.0' encoding='utf-8'?>
<robot name="Chapter">
    <link name="Revolute-to-right-angle-revolute-v1_Revolute-to-right-angle-revolute">
        <inertial>
            <origin xyz="6.261948856349923e-19 0.046489243677971075 2.303928612288049e-21" rpy="0.0 0.0 0.0" />
            <mass value="0.08639778695369857" />
            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
        </inertial>
        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
    </link>
    <link name="Right-angle-revolute-to-middle-acting-revolute-v1_right-angle-revolute-to-middle-acting-revolute">
        <inertial>
            <origin xyz="0.029979542226560095 1.5265566588595902e-16 0.05712841655809005" rpy="0.0 0.0 0.0" />
            <mass value="0.1379892560903595" />
            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
        </inertial>
        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
    </link>
    <link name="Base-with-revolute-v1_Base-with-revolute-on-it">
        <inertial>
            <origin xyz="0.012145617090068126 0.010632082163354617 0.026489300642834303" rpy="0.0 0.0 0.0" />
            <mass value="0.8620671947833745" />
            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
        </inertial>
        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
    </link>
    <link name="Right-Angle-middle-acting-revolute-to-revolute-v1_Right-angle-middle-acting-revolute-to-revolute">
        <inertial>
            <origin xyz="0.041047168655963556 0.010465048118174473 0.01250000000000471" rpy="0.0 0.0 0.0" />
            <mass value="0.11840470364111966" />
            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
        </inertial>
        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
    </link>
    <link name="Middle-acting-revolute-to-revolute-v1_Middle-acting-revolute-to-revolute">
        <inertial>
            <origin xyz="2.2452595360190897e-08 0.01389283522724914 0.012499993025155445" rpy="0.0 0.0 0.0" />
            <mass value="0.06809250514511168" />
            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
        </inertial>
        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
    </link>
    <link name="Revolute-to-middle-acting-revolute-v1_Revolute-to-middle-acting-revolute">
        <inertial>
            <origin xyz="0.021020834207110026 -1.736458199452784e-15 5.0133508455729725e-16" rpy="0.0 0.0 0.0" />
            <mass value="0.07226389748005418" />
            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
        </inertial>
        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
    </link>
    <link name="Revolute-to-end-effector-v1_Revolute-to-end-effector">
        <inertial>
            <origin xyz="-2.0132724968483645e-13 0.022676889315266124 7.298849025172416e-16" rpy="0.0 0.0 0.0" />
            <mass value="0.05712737965985806" />
            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
        </inertial>
        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
    </link>
    <joint name="Base-with-revolute-v1_Base-with-revolute-on-it_Revolute-1" type="continuous">
        <origin xyz="0.01214562 0.11 0.0264893" rpy="-1.5707963267948966 -0.0 0.0" />
        <parent link="Base-with-revolute-v1_Base-with-revolute-on-it" />
        <child link="Revolute-to-right-angle-revolute-v1_Revolute-to-right-angle-revolute" />
        <axis xyz="0.0 0.0 1.0" />
    </joint>
    <joint name="Revolute-to-right-angle-revolute-v1_Revolute-to-right-angle-revolute_Revolute-2" type="continuous">
        <origin xyz="0.00750000365964836 0.08750000000000001 3.571816113989712e-09" rpy="-6.123233995710782e-17 -1.5671170916725328 3.141592653589793" />
        <parent link="Revolute-to-right-angle-revolute-v1_Revolute-to-right-angle-revolute" />
        <child link="Right-angle-revolute-to-middle-acting-revolute-v1_right-angle-revolute-to-middle-acting-revolute" />
        <axis xyz="-0.003679 1.2312517577372591e-32 0.999993" />
    </joint>
    <joint name="Right-angle-revolute-to-middle-acting-revolute-v1_right-angle-revolute-to-middle-acting-revolute_Revolute-3" type="revolute">
        <origin xyz="0.022499996781836656 1.1736162797149063e-09 0.11249999796721688" rpy="-1.564423805269457 -1.0471858281412112 -1.5781546974323617" />
        <parent link="Right-angle-revolute-to-middle-acting-revolute-v1_right-angle-revolute-to-middle-acting-revolute" />
        <child link="Right-Angle-middle-acting-revolute-to-revolute-v1_Right-angle-middle-acting-revolute-to-revolute" />
        <axis xyz="-0.003679 -4.336778332281188e-19 0.999993" />
        <limit lower="0.0" upper="3.141593" effort="1000000" velocity="1000000" />
    </joint>
    <joint name="Right-Angle-middle-acting-revolute-to-revolute-v1_Right-angle-middle-acting-revolute-to-revolute_Revolute-4" type="continuous">
        <origin xyz="0.10499999720750319 0.014999998020509046 0.012499999333170714" rpy="-3.1415926535897776 -0.003679235122342751 1.012290966156807" />
        <parent link="Right-Angle-middle-acting-revolute-to-revolute-v1_Right-angle-middle-acting-revolute-to-revolute" />
        <child link="Revolute-to-middle-acting-revolute-v1_Revolute-to-middle-acting-revolute" />
        <axis xyz="0.5299159999999999 0.8480479999999998 0.0019500000000000936" />
    </joint>
    <joint name="Revolute-to-middle-acting-revolute-v1_Revolute-to-middle-acting-revolute_Revolute-5" type="revolute">
        <origin xyz="0.032499995346262446 1.3477801985573023e-10 -0.012499996754991685" rpy="0.5610261306533012 -0.913036541090983 1.5676071379089398" />
        <parent link="Revolute-to-middle-acting-revolute-v1_Revolute-to-middle-acting-revolute" />
        <child link="Middle-acting-revolute-to-revolute-v1_Middle-acting-revolute-to-revolute" />
        <axis xyz="0.791364 0.32527000000000006 0.517632" />
        <limit lower="0.0" upper="3.141593" effort="1000000" velocity="1000000" />
    </joint>
    <joint name="Middle-acting-revolute-to-revolute-v1_Middle-acting-revolute-to-revolute_Revolute-6" type="continuous">
        <origin xyz="1.0291060270617437e-09 0.04250000550666402 0.0124999973023807" rpy="2.131822457448252 0.9130365410910117 0.6987424699700375" />
        <parent link="Middle-acting-revolute-to-revolute-v1_Middle-acting-revolute-to-revolute" />
        <child link="Revolute-to-end-effector-v1_Revolute-to-end-effector" />
        <axis xyz="0.3932509999999999 0.023648000000000047 -0.919127" />
    </joint>
</robot>

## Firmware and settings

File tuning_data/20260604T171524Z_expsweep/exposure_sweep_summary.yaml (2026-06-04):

kind: exposure_sweep
utc: 20260604T171524Z
iso: 3200
exposures_us:
- 8000
- 6000
- 4000
- 3000
- 2000
- 1500
- 1000
- 750
- 500
oak_config_at_start:
  rgb_fps: 60
  mono_fps: 15
  jpeg_quality: 50
  focus_mode: manual
  focus_pos: 130
  exp_us: 8000
  iso: 1600
  v0_backend: cv2
  v0_blob: null
  v1_blob: v1_yolov8n_320.blob
  v1_arch: v8
  nn_conf_min: 0.0001
  v1_yolo_conf_min: 0.3
  jpeg_fps: 10
  hsv_lo:
  - 5
  - 100
  - 60
  hsv_hi:
  - 22
  - 255
  - 255
  enable_depth: false
  mask_v0_to_platform: true
  usb_speed: super
  rgb_w: 960
  rgb_h: 540
original_exp_us: 8000
original_iso: 1600
best_detect_hz: 11.45
recommended_exp_us: 1500
recommendation_note: shortest exposure holding detect_hz >= 90% of best (11.4 Hz).
  Verify saturation stays above the HSV gate and re-test detection under a MOVING
  ball before adopting.
rows:
- exp_us: 8000
  iso: 3200
  detect_hz: 11.43
  frame_hz: 8.45
  detect_frac: 1.353
  latency_mean: 130.2
  latency_std: 35.0
  latency_p95: 190.9
  sat_mean: 39.5743
  sat_p50: 10.6234
  val_mean: 194.227
  over_clip_frac: 0.2912
  under_clip_frac: 0.0007
  mean: 185.9201
  tenengrad: 40046.0244
- exp_us: 6000
  iso: 3200
  detect_hz: 9.73
  frame_hz: 7.24
  detect_frac: 1.345
  latency_mean: 131.7
  latency_std: 35.7
  latency_p95: 186.0
  sat_mean: 48.2783
  sat_p50: 13.7908
  val_mean: 186.7767
  over_clip_frac: 0.057
  under_clip_frac: 0.0019
  mean: 177.7781
  tenengrad: 40524.256
- exp_us: 4000
  iso: 3200
  detect_hz: 11.2
  frame_hz: 7.47
  detect_frac: 1.5
  latency_mean: 128.3
  latency_std: 38.6
  latency_p95: 185.2
  sat_mean: 52.4903
  sat_p50: 13.3399
  val_mean: 160.5262
  over_clip_frac: 0.0
  under_clip_frac: 0.0038
  mean: 152.0665
  tenengrad: 33897.1102
- exp_us: 3000
  iso: 3200
  detect_hz: 10.24
  frame_hz: 7.99
  detect_frac: 1.281
  latency_mean: 128.7
  latency_std: 34.1
  latency_p95: 195.6
  sat_mean: 57.8143
  sat_p50: 13.2451
  val_mean: 142.4503
  over_clip_frac: 0.0
  under_clip_frac: 0.0074
  mean: 134.7667
  tenengrad: 28750.2064
- exp_us: 2000
  iso: 3200
  detect_hz: 11.19
  frame_hz: 8.95
  detect_frac: 1.25
  latency_mean: 120.3
  latency_std: 28.6
  latency_p95: 167.6
  sat_mean: 64.1238
  sat_p50: 13.5051
  val_mean: 118.6364
  over_clip_frac: 0.0
  under_clip_frac: 0.0177
  mean: 112.0923
  tenengrad: 21059.5593
- exp_us: 1500
  iso: 3200
  detect_hz: 11.45
  frame_hz: 8.22
  detect_frac: 1.394
  latency_mean: 121.5
  latency_std: 28.1
  latency_p95: 170.0
  sat_mean: 66.9935
  sat_p50: 12.8481
  val_mean: 102.0036
  over_clip_frac: 0.0
  under_clip_frac: 0.0294
  mean: 96.1597
  tenengrad: 15620.1964
- exp_us: 1000
  iso: 3200
  detect_hz: 0.25
  frame_hz: 8.7
  detect_frac: 0.029
  latency_mean: 98.3
  latency_std: 22.3
  latency_p95: 134.2
  sat_mean: 57.6092
  sat_p50: 12.0621
  val_mean: 79.4396
  over_clip_frac: 0.0
  under_clip_frac: 0.0699
  mean: 75.3784
  tenengrad: 9791.0303
- exp_us: 750
  iso: 3200
  detect_hz: 0.0
  frame_hz: 9.21
  detect_frac: 0.0
  latency_mean: 101.9
  latency_std: 25.6
  latency_p95: 142.4
  sat_mean: 47.8097
  sat_p50: 0.6144
  val_mean: 64.4581
  over_clip_frac: 0.0
  under_clip_frac: 0.1043
  mean: 61.4525
  tenengrad: 6570.4227
- exp_us: 500
  iso: 3200
  detect_hz: 0.0
  frame_hz: 9.22
  detect_frac: 0.0
  latency_mean: 95.2
  latency_std: 24.6
  latency_p95: 128.5
  sat_mean: 38.9501
  sat_p50: 0.0
  val_mean: 44.9334
  over_clip_frac: 0.0
  under_clip_frac: 0.1633
  mean: 42.8021
  tenengrad: 3235.4181

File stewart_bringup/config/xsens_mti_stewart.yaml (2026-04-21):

/**:
    ros__parameters:
        # Device Scanning Configuration
        # -----------------------------
        # This section allows you to configure how the ROS driver searches for devices.
        # You have two options:
        # 1. Automatic scanning for devices.
        # 2. Manual specification of port and baudrate.

        # STEWART BRING-UP (2026-04-20):
        # - scan_for_devices=true - explicit scanPort path fails reliably with
        #   our FTDI+MTi combo; multi-port scan works reliably.
        # - baudrate 921600 - set via MT Manager on Windows after an
        #   unbind/reattach cycle. Both boards (DBBBRHGX + DBBBRHBS) were
        #   configured to UART Xbus at 921600 on 2026-04-20.
        scan_for_devices: true
        # port: '/dev/imu_mti630'
        baudrate: 921600

        # Device Scanning Selection
        # ----------------
        # Specify the device ID when operating multiple devices to select a specific one.
        # Format: Uppercase hexadecimal string.
        # Example: device_id: '00800210C2'
        #device_id: '00800210C2'

        # Publisher Configuration
        publisher_queue_size: 5

        # Time Options
        # ------------
        # Choose how timestamps are generated for the ROS Node:
        # 1) 0: Use UTCTime from MTI, recommended for accurate time synchronization.
        # 2) 1: Use UTCTime based on the SampleTimeFine from MTI.
        # 3) 2: Use UTCTime from the host device.
        # Note: Ensure "UTC Time" or "Sample Time Fine" is selected in MT Manager under Device Settings > Output Configurations, 
        # or you could also set 'enable_deviceConfig: true' for once to configure output.
        time_option: 0

        # Logging Configuration
        # ---------------------
        # Enable or disable logging of sensor data into .mtb file. If enabled, logs are stored in /home/[user_name]/Documents/xsens_log.
        enable_logging: false

        # Transform Frame ID
        # ------------------
        # Default frame_id is "imu_link". Change this if using multiple devices to avoid conflicts.
        # frame_id: "imu_link"


        # Sensor Configuration
        # ---------------------------
        # If you want to configure your sensor, firstly set this flag to true, then change desired values for the parameters below.
        # Note: This configuration is required only once, once it is successful, the configurations are stored in the sensor, then you could set this to false.
        # STEWART: leave true on first launch so output_data_rate=400 and the disabled
        # GNSS publishers get pushed into NVM. Flip to false after first successful
        # launch so startup is faster and we don't re-config every boot.
        enable_deviceConfig: true

        # Sensor Extended Kalman Filter Option Configurations:
        # --------------------------
        # ref: https://base.movella.com/s/article/article/MTi-Filter-Profiles-1605869708823
        # If you want to configure the filter option, firstly set the 'enable_filter_config', then:
        # For MTi-3/7/8/30/300/G-710/670(G)/680(G): change the 'mti_filter_option' to desired index below for your model.
        # For MTi-620(R)/MTi-630(R), and Sirius/Avior VRU/AHRS models:   change the 'filter_label_rollpitch' and 'filter_label_yaw' to the exact labels.
        enable_filter_config: false
        # ---------------------------
        # For MTi-670(G): 3 options: 0 = "General", 1 = "GeneralNoBaro", 2 = "GeneralMag"
        # For MTi-680(G), 3 options: 0 = "General_RTK", 1 = "GeneralNoBaro_RTK", 2 = "GeneralMag_RTK"
        # For MTi-3: 4 options: 0 = "general", 1 = "high_mag_dep", 2 = "dynamic", 3 = "north_reference", 4 = "vru_general"
        # For MTi-320: 1 option: 0 = "vru_general"
        # For MTi-7:  3 options: 0 = "General", 1 = "GeneralMag",  2 = "GeneralNoBaro"
        # For MTi-8: 3 options: 0 = "General_RTK", 1 = "GeneralNoBaro_RTK", 2 = "GeneralMag_RTK"
        # For MTi-300: 0 = "general", 1 = "high_mag_dep", 2 = "dynamic", 3 = "lwo_mag_dep", 4 = "vru_general"
        # For MTI-G-710: 3 options: 0 = "General", 1 = "GeneralNoBaro",  2 = "GeneralMag", 3 = "Automotive", 4 = "HighPerformanceEDR"
        mti_filter_option: 0

        # For MTi-620(R)/MTi-630(R), and Sirius/Avior VRU/AHRS models:  roll pitch options: "Responsive", "General", "Robust"
        filter_label_rollpitch: "Robust"
        # MTI-620(R) and Sirius/Avior VRU models, yaw has 2 options: "VRU", "VRUAHS" 
        # MTI-630(R) and Sirius/Avior AHRS models, yaw has 3 options: "FixedMagRef", "NorthReference", "VRU", "VRUAHS" 
        filter_label_yaw: "NorthReference"


        # MTi-2/320/200: filter only has VRU, you could enable the AHS options:
        # valid for MTI-2/3/320, MTi-20/30, MTI-200/300 when using the VRU filter options.
        enable_active_heading_stabilization: false
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

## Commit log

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2026-04-27 Level-PI tuning: instrumentation + GUI + auto-sweep (Phase 1+2)
    Per stewart_bringup/docs/level_pi_tuning_plan.md, the level loop
    limit-cycles instead of settling inside the 0.1° error band; this
    commit lands the data-collection infrastructure so the gains can
    be tuned data-driven rather than by hand.
    Control node:
    - LevelDiag.msg in jugglebot_interfaces — per-tick controller state
    (raw + filtered err, integ, unclipped pi_out, post-clip corr,
    clip-flags bitfield, motor_targets/leg_enc/leg_iq, dt, target_xyzrpy
    including Z so bags are self-describing).
    - _level_run rewritten to use config/level_gains.yaml (live-reloadable),
    honor an external integrator-reset request, accept step of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
    [level_gains.yaml]
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2026-04-27 Phase 3: bag analyzer + tuning_data digest workflow
    scripts/analyze_level_bag.py reads /level_diag from a single bag dir
    or a sweep_*/ dir via rosbag2_py and writes:
    tuning_data/<name>/<name>_summary.json
    tuning_data/<name>/<name>_timeseries.csv (50 Hz → 10 Hz downsampled)
    tuning_data/<sweep>/<sweep>_sweep_summary.json (per-Z rollup)
    Summary covers baseline (RMS, p2p, FFT peak, saturation breakdown by
    clip flag), per-step metrics (rise 10→90, overshoot %, 1%-settling
    into the 0.1° band, ss-offset), aggregated across positive-amp trials
    with per-trial pre-step mean subtraction. Sweep mode walks
    manifest.json and emits Z-vs-{rms, fft_peak, rise, overshoot,
    settling, ss_offset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
    [analyze_level_bag.py]
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2026-04-27 Analyzer: auto-detect mcap vs sqlite3 storage
    Kilted's rosbag2 default is mcap; the analyzer hardcoded sqlite3 so
    it failed on every Pi-recorded bag with "file is not a database".
    Now reads metadata.yaml's storage_identifier (authoritative) and
    falls back to file extension (*.mcap → mcap, *.db3 → sqlite3,
    default mcap).
    [analyze_level_bag.py]
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2026-04-27 level_gains.yaml: iteration 2 (faster transient + tighter deadband)
    Iter-1 sweep at the original gains (sweep_20260427T154540Z) showed:
    - Static RMS at Z=40-50 was already ≤0.07° (near spec).
    - Every step trial peaked well below 1° in the 3 s hold —
    transient response was too slow for the cascade ball loop.
    - Saturation breakdown was 86% deadband_p / 29% deadband_r,
    no rate-limit, no max-corr — i.e. the deadband was freezing
    the integrator while ~0.08 Hz drift accumulated.
    Changes for iter-2:
    - kp 0.7 → 1.5 faster proportional response
    - ki 0.2 → 0.5 faster integral wind-up
    - deadband 0.05 → 0.02 below MTi-630 noise floor; lets the integ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
    [level_gains.yaml]
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2026-04-27 level_gains.yaml: iteration 3 (bisect KP/KI back toward stability)
    Iter-2 sweep (sweep_20260427T164414Z) caused a 0.4 Hz controller-driven
    limit cycle at Z=30-50 mm with ±0.55° amplitude — RMS jumped 2-8× vs
    iter-1 across the operating range. Z=25 improved 8× though, telling us
    the deadband=0.02 change was correct on its own; the simultaneous 2.5×
    KP and 2.5× KI bumps were what crossed the stability margin.
    Iter-3 keeps deadband=0.02 and bisects KP/KI between iter-1 (stable
    but slow) and iter-2 (fast but oscillating):
    - kp 1.5 → 1.0 (iter-1 was 0.7)
    - ki 0.5 → 0.3 (iter-1 was 0.2)
    - rate_limit 0.3 → 0.25 (iter-1 was 0.2)
    Expected outcome: stable across Z=30-55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
    [level_gains.yaml]
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2026-04-27 Capture leg velocity + iq setpoint for ODrive feedforward A/B test
    Adds two LevelDiag fields so we can see what the inner loop is actually
    doing on a per-tick basis:
    leg_vel[6] — actual leg velocity (turns/s), already in the same
    Get_Encoder_Estimates frame as pos; previously dropped
    leg_iq_sp[6] — commanded Iq from the ODrive controller; pairs with
    the existing iq_measured to show electrical tracking
    Use case: about to flip on wL_FF_enable + vel_integrator_gain on each
    ODrive (per Solomon@ODrive), and want before/after data showing the
    inner-loop tracking change. With both vel and iq_sp recorded we can
    plot:
    - vel_n vs (mt_n - mt_n_prev)/d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
    [analyze_level_bag.py]
2026-04-27 Batch ODrive feedforward configurator (apply / revert / status)
    scripts/set_odrive_feedforward.py — discovers every USB-attached ODrive
    and sets vel_integrator_gain + wL_FF_enable in one shot rather than
    making the operator paste 4 lines into odrivetool 6×.
    Modes:
    --apply (default) — record current values to backup file keyed by
    serial number, set new values, save_configuration
    --status — print current values, change nothing
    --revert — restore previous values from backup
    Safety: refuses to change config unless every axis is in IDLE state.
    Backup file at ~/.stable_bot_odrive_ff_backup.json accumulates across
    runs (single-USB-cable w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
    [set_odrive_feedforward.py]
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2026-04-27 set_odrive_feedforward.py: clear CAN-not-supported error on odrive 0.6.x
    odrive 0.6.10's Python library rewrite (around libodrive) shipped
    without a CAN transport — odrivetool --help only lists usb and serial,
    find_sync has no path arg, and DeviceManager has no add_can_* hook.
    This is a regression from the older 0.5.x library which did support
    CAN (which is what Solomon@ODrive's "use odrivetool over CAN" advice
    was based on).
    Rather than have the script silently fail with cryptic
    "find_sync() got unexpected keyword argument 'path'", detect that
    the library lacks CAN support up front (look for path/transport
    kwarg on find_sync, or add_can_* method on DeviceManager) and exit
    with a clear er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
    [set_odrive_feedforward.py]
2026-04-27 ODrive FF: one-USB-then-CAN-only configurator (fw 0.6.11)
    Two-script pair that gets ODrive feedforward enabled on all 6 drives
    without 6× USB cable swaps.
    dump_odrive_endpoints.py — USB, run ONCE per firmware version.
    Connects to any single ODrive, walks the parameter tree using
    defensive reflection (multiple known patterns: leaf._id, leaf._endpoint_id,
    parent._remote_attributes[name].id, etc.), saves the IDs we need
    (vel_integrator_gain, wL_FF_enable, save_configuration) into
    stewart_bringup/data/odrive_endpoints.json keyed by firmware version.
    On extraction failure, dumps the parent attribute table so we can
    patch the reflection logic without another USB-connect cycle.
    set_odrive_feed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
    [dump_odrive_endpoints.py, set_odrive_feedforward_via_can.py]
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2026-04-27 ODrive endpoint IDs (fw 0.6.11), patched dump reflection
    odrive 0.6.10 (sync_tree/async_tree) stores property metadata behind
    a `parent._<name>_property._info` indirection (PropertyInfo with
    endpoint_id + codec_name + writable). Function endpoints store
    metadata on `leaf._info` (FunctionInfo with endpoint_id + inputs +
    outputs). The dump script's earlier reflection paths missed both;
    patched to try those first, with the older fallbacks kept.
    Endpoint IDs from one USB probe of axis serial 0x347D35583233
    (hw 4.4-58, fw 0.6.11):
    axis0.controller.config.vel_integrator_gain → 382 (float32)
    axis0.config.motor.wL_FF_enable → 305 (bool)
    save_configuration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
    [odrive_endpoints.json]
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2026-04-28 Add CAN-only endpoint diff probe
    Pure CAN, no USB, no library. Iterates SDO endpoint IDs across two
    or more nodes, reads the raw 4-byte response from each, reports
    endpoints where they differ.
    Use case: nodes 2 and 5 silently revert vel_integrator_gain writes
    (verify reads back values different from what we wrote AND different
    from the prior value — classic autotune behaviour). Whatever config
    flag enables the autotune on those drives will show up in the diff
    output. Once we know the endpoint id, the existing CAN write
    infrastructure can disable it.
    Outputs interpret each 4-byte payload as float32 / int32 / uint32 /
    bool so the operator can pattern-match the type without having
    to know i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
    [probe_odrive_config_via_can.py]
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2026-04-28 Per-drive identity + config backup wrapper
    inventory_and_backup_odrive.py — per ODrive, plug USB and run this
    script (no manual copy-paste). It connects via USB, reads
    sn/hw/fw/commit/can_node, writes:
    <out>/odrv_node<N>_sn<SN>.txt — identity values for the inventory
    <out>/odrv_node<N>_sn<SN>.json — odrivetool backup-config output
    Default <out> is ~/odrive_backups_YYYYMMDD/. Filenames auto-derive
    from the actual node id + serial we read from the drive, so there's
    no manual substitution and no wrong-filename risk.
    Replaces the two-step "open odrivetool, exit, run backup-config with
    manually-typed filename" workflow from REFLASH_FIRMWARE.md. Per-drive
    loop becomes:
    plug USB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
    [inventory_and_backup_odrive.py]
2026-04-28 inventory_and_backup_odrive.py: identity read in subprocess
    The previous version had odrive.find_any() in the parent process,
    then expected del+gc+sleep to release the USB handle before shelling
    out to odrivetool backup-config. Doesn't work — odrive 0.6.10's
    libodrive C++ runtime keeps the device claimed until the *process*
    exits. odrivetool backup-config hung indefinitely.
    Fix: run the identity read as a subprocess too, so when it exits
    the USB handle is fully released. Parent process now does no
    direct USB I/O — only orchestrates two children (identity probe,
    then odrivetool backup-config).
    Also adds --no-backup flag for cases where you only want the
    identity readout (e.g. the invent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
    [inventory_and_backup_odrive.py]
2026-04-28 inventory_and_backup_odrive.py: explicit close_device_manager + 3s settle
    The previous fix (run identity probe in subprocess) wasn't enough on
    its own. atexit hooks weren't firing reliably for the odrive 0.6.10
    device manager when the subprocess exited, so libodrive's C++
    runtime kept USB claimed for several seconds — long enough that
    the immediate-follow-up odrivetool backup-config call hung past
    its 120 s timeout.
    Two changes:
    1. The identity probe explicitly calls
    `odrive.device_manager.close_device_manager()` in a finally
    block before sys.exit(). This signals libodrive to tear down
    its threads and release USB endpoints synchronously rather
    than relying on process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
    [inventory_and_backup_odrive.py]
2026-04-28 inventory_and_backup_odrive.py: drop auto-invoke; print the manual command
    Even with explicit close_device_manager() and a multi-second settle
    gap, libodrive 0.6.10's USB lifecycle is too sticky to chain a
    subprocess `odrivetool backup-config` cleanly after a Python identity
    probe in the same script run. The user already confirmed manual
    `odrivetool backup-config` runs cleanly when invoked in a fresh shell
    after the previous odrivetool call exits — it's specifically the
    back-to-back machine-paced timing that fails.
    Removed the auto-invoke. Script now does identity probe + writes .txt
    + prints the exact next command for the operator to run. Two commands
    per drive (script + odrivetool backu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
    [inventory_and_backup_odrive.py]
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2026-04-28 FF configurator step 2: vel_integrator_gain 0.05 → 0.333 (ODrive stock)
    Step 1 (motor recalibration) didn't fix the regression — fresh
    inductance values gave equally bad or slightly worse results
    (sweep_20260428T155232Z confirms: RMS_r at Z=25/30/35 = 0.70/0.59/0.57
    vs pre-recal 0.42/0.12/0.67). Inductance was not the culprit.
    Step 2: bump vel_integrator_gain back to ODrive's stock default
    0.333 while keeping wL_FF_enable=True. Tests whether the under-gained
    inner velocity loop was making wL_FF erratic, or whether wL_FF is
    fundamentally not playing well with this hardware/firmware combo.
    If this sweep recovers iter-3 pre-fix RMS (~0.04° at Z=35), the
    0.05 vel_integrator_gain was the p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
    [set_odrive_feedforward_via_can.py]
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2026-04-28 FF configurator step 3: wL_FF_enable False (full ODrive defaults)
    Step 2 sweep (sweep_20260428T160636Z) showed wL_FF contribution is
    non-monotonic in Z:
    Z=25: 0.46 (vs 0.24 pre-fix) — worse
    Z=30: 0.13 (vs 0.15 pre-fix) — same
    Z=35: 0.15 (vs 0.04 pre-fix) — much worse
    Z=40: 0.07 (vs 0.11 pre-fix) — better
    Z=45: 0.12 (vs 0.06 pre-fix) — worse
    Z=50: 0.21 (vs 0.13 pre-fix) — worse
    Z=55: 0.07 (vs 0.13 pre-fix) — better
    A knob that helps 2 Zs and hurts 5 isn't a knob worth keeping —
    the wrong tradeoff for any single operating point. Drop wL_FF
    entirely so the inner velocity loop returns to ODrive factory
    defaults. Should reproduce iter-3 pre-fix performance now that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
    [set_odrive_feedforward_via_can.py]
2026-04-28 FF configurator: --vel-integrator-gain + --wl-ff CLI flags
    No more editing DEFAULT_TARGETS + commit + push to flip a single
    knob. The script now accepts:
    --vel-integrator-gain GAIN (float; overrides default for that endpoint)
    --wl-ff true|false (bool; overrides default for that endpoint)
    Either or both can be omitted, in which case the matching value
    from DEFAULT_TARGETS is used (preserving prior behavior). All three
    modes (--apply, --status, --revert) honor the same override flags.
    apply mode now prints a banner showing exactly what's about to be
    written before doing the backup + write cycle:
    Targets for this run:
    axis0.controller.config.vel_integrator_gain = 0.333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
    [set_odrive_feedforward_via_can.py]
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2026-04-28 Configurator: --control-mode, --input-mode, --clear-errors flags
    For recovering from watchdog-disarm + persistent VELOCITY_CONTROL mode
    without USB cable shuffles. Adds 4 new endpoint targets to the dump
    script (control_mode, input_mode, clear_errors as a function, plus
    the previously-added encoder_msg_rate_ms) and three new flags to the
    CAN configurator:
    --control-mode {voltage,torque,velocity,position}|0..3
    --input-mode {inactive,passthrough,vel_ramp,pos_filter,...,tuning}|0..8
    --clear-errors (action flag — calls clear_errors() on each axis
    after writes, before save)
    All flags are optional. --apply without them only writes the
    DEFAULT_TARGETS entries (vel_inte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
    [dump_odrive_endpoints.py, set_odrive_feedforward_via_can.py]
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2026-04-28 LevelDiag: yaw, axis_state, active_errors, feeder_mode
    Surfaces silent disarms, watchdog/vel-limit hits, and feeder-mode
    mismatches in the bag instead of leaving them as guesswork. Three
    classes of "level-doesn't-work" all looked identical from outside
    (IMU error stays huge, corrections saturate, platform doesn't move) —
    now they're separable from a single 15 s bag.
    Listener: handle Heartbeat (cmd 0x001) for axis_state. Native 10 Hz
    broadcast, no RTR overhead. Existing Get_Error feed re-used for
    active_errors. Feeder.get_modes() existed already.
    Analyzer: new 'health' block at the top of every per-bag summary —
    per_leg_state (with first_drop_t_s), per_leg_active_errors (decoded
    to name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
    [analyze_level_bag.py]
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2026-04-29 analyze_level_bag: scrub NaN/Inf before json.dump
    Same class of bug as gui_server's /bags handler — Python's
    json.dump emits non-finite floats as NaN/Infinity tokens that
    break strict-JSON parsers. The digest's summary.json carries
    inner_loop_config from the sidecar (which can contain
    vel_integrator_limit=+inf) and stats from numpy aggregations
    (which propagate NaN if any sample has NaN encoder readings).
    _finite_scrub matches the helper in gui_server.py and the node's
    _scrub_non_finite. Three copies, intentionally — each is at the
    boundary it owns.
    [analyze_level_bag.py]
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2026-04-29 Configurator: --current-soft-max for persistent per-axis current cap
    The GUI's set_leg_current sends CAN cmd 0x00F (Set_Limits) which is
    runtime-only by ODrive's own protocol spec — the value reverts to
    flash on disarm/reboot. 2026-04-29 the platform jammed at -3.6° tilt
    with legs 0/5 saturated at 6 A despite the user setting 11 A in the
    GUI; the inner_loop_config snapshot showed all 6 drives still at
    flash default 6.0 A.
    Adds:
    - --current-soft-max AMPS flag → writes axis0.config.motor.current_soft_max
    via SDO and save_configuration() persists it.
    - Endpoint id=315 added to odrive_endpoints.json (verified against
    official 0.6.11-1 flat_endpoints.json).
    Standard one-shot now become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
    [odrive_endpoints.json]
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2026-04-29 compare_bags: handle sweep-child paths + missing-dir defaults
    - _find_bags_in_dir now treats <sweep_dir>/<child_prefix> as a
    virtual prefix when no real dir exists at that path. Lets you
    cherry-pick a single Z out of a sweep without globbing.
    - Removed the early dp.exists() check in main so virtual paths
    reach the resolver.
    - Default --out-plot now falls back to first.parent or cwd if
    the first input isn't a real dir, so writing the overlay PNG
    doesn't crash on virtual prefixes.
    [compare_bags.py]
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2026-04-29 IVA: fix quaternion math + Push-to-GitHub button per bag
    Three changes after analyzing 20260429T181703Z_imu_vs_camera bag.
    (1) JS: relative quaternion in PLATFORM frame, not camera frame
    The IMU-vs-Camera panel was computing q_rel = q_now * conj(q_ref),
    which is the platform's rotation expressed in the CAMERA frame.
    When the camera mount inverts +X relative to the platform (typical
    for an overhead camera looking down at the operator-facing side),
    this anti-correlates the displayed roll with IMU roll — Δp95 = 3.94°
    on a near-static bag, all from the axis flip.
    The correct formula for tilt expressed in PLATFORM frame (matching
    IMU semantics) is q_rel = conj(q_ref) * q_no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
    [digest_iva_bag.py]
2026-04-29 digest_iva_bag: auto-detect rosbag2 storage, fall back to .mcap file
    ROS 2 Kilted's rosbag2 rejects StorageOptions(uri=<dir>, storage_id='mcap')
    — the mcap plugin tries to open the directory as a file and bails:
    Could not open '<dir>' with 'mcap'. Error: read failed
    No storage could be initialized for the input URI
    Fix: use empty storage_id='' so rosbag2 reads metadata.yaml and
    picks the correct plugin itself (works for both mcap and sqlite3
    bags). Falls back to enumerating .mcap files in the directory and
    trying each with explicit storage_id='mcap' if the auto-detect path
    also fails (handles older / weirder rosbag2 versions defensively).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
    [digest_iva_bag.py]
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2026-04-29 digest_iva_bag: auto-calibrate IMU↔ArUco rotation per bag
    User request 2026-04-29: take IMU as ground truth and solve for the
    constant rotation+reflection between IMU body axes and the ArUco
    platform frame from the bag itself, applying it to the camera
    readings before computing residuals.
    The 20260429T183540Z sweep showed yaw p95 < 0.25° (clean) but
    roll anti-correlated with IMU and pitch with a 1° static offset —
    classic IMU-mount-rotation symptom. The math is 2D Procrustes:
    find orthogonal M minimizing
    Σ ‖M · cam_rp_i − imu_rp_i‖²
    across all bag samples. Allowing det(M) = ±1 captures both pure
    rotation and reflection, so an X-flipped IMU mount is handled.
    Implementa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
    [digest_iva_bag.py]
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2026-04-30 Demos: live-editable BALL_TRACK gains panel + demo bag pipeline
    Ends the guess-and-check tuning loop. Every adjustment is now made
    live from the GUI (no service restart) and every run produces a
    digest artifact you can compare against the next one.
    - config/ball_track_gains.yaml is the new source of truth for
    the BALL_TRACK PID. _load_ball_track_gains() at startup, env
    vars retained as one-shot override.
    - _do_ball_track_save_gains(d): partial-dict save (typo guard
    via known-keys whitelist + bounds clamp), atomic tmp+rename,
    in-memory reload. Loop picks up new gains within one tick.
    - _do_ball_track_reload_gains(): re-read disk (Revert p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
    [ball_track_gains.yaml, digest_demo_bag.py]
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2026-04-30 Demo digest: parse + surface demo_mode + full demo_params
    Demo runs are tuned by sweeping the GUI's per-demo params (radius,
    n_waypoints, arrival_tol_mm, dwell_s, max_wait_s, dir, mode toggle,
    period_s) AND the BALL_TRACK gains (kp, kd, ki, max_tilt, signs).
    The previous digest only captured the gains — comparing two bags
    to figure out what changed required digging into the raw mcap or
    journal output.
    digest_demo_bag.py:
    - New _parse_control_cmd handles all three /control_cmd formats
    the GUI emits (key:value, mode:NAME json, raw json) — the old
    parser tried json.loads on every message and silently bucketed
    failures into {'raw': ...}, which is why mode commands never
    sh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
    [digest_demo_bag.py]
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2026-04-30 ArUco↔IMU alignment: wire IVA Procrustes into ball_localizer
    User's call: stop guessing sign conventions; measure the frame
    mismatch empirically and feed the result back into the live
    system. The IVA sweep already does the measurement (Procrustes
    2x2 rotation + reflection between cam and IMU rpy in the digest);
    it just wasn't reaching ball_localizer. Latest IVA bag confirms
    the rotation is real and tight: 149°, det=+1.0, RMS=0.13°. No
    combination of pitch_sign/roll_sign can compensate a 149° offset
    — the loop genuinely needs the continuous rotation correction.
    digest_iva_bag.py:
    After computing the alignment matrix M, write it as a standalone
    aruco_imu_alignment.yaml next to the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
    [digest_iva_bag.py]
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2026-04-30 Bang-bang controller alternative + Demo 2 stop SVG cleanup
    User describes a finite-state-machine control scheme: ACCELERATE
    (full tilt toward target) → COAST (level when ball moving toward
    target) → BRAKE (full opposite tilt when about to overshoot) →
    SETTLE (zero tilt within tolerance). Implement as opt-in
    algorithm alongside existing PID.
    ball_track_gains.yaml + _load_ball_track_gains():
    - New 'algorithm' field: 'pid' (default) | 'bangbang'.
    - Bang-bang thresholds: accel_tilt_deg, err_tol_mm, v_brake_mm_s,
    v_coast_mm_s, brake_horizon_mm. Each has physical meaning,
    easier to tune than PID gains (interaction-free).
    - _BALL_TRACK_GAIN_BOUNDS extende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
    [ball_track_gains.yaml]
2026-04-30 Demo digest 20260430T050820Z_demo2
    label=demo2 mode=BALL_TRACK_GOTO duration=44.5s settling=None
    error_mm: rms=210.5 p95=256.4 max=326.2
    gains: kp=0.01 kd=0.015 ki=0.005 max_tilt=4.0deg signs(p/r)=1.0/1.0
    demo_params: x_mm=-53.10342788696289 y_mm=7.586187839508057
    Digest only (digest.png + digest.summary.json). Raw rosbag2 mcap stays on the Pi.
    [ball_track_gains.yaml, leg_limits.yaml, level_gains.yaml]
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2026-04-30 Bang-bang: per-tick phase telemetry + stiction breakthrough
    Three failed bang-bang demo2 runs (rms 210, 194, 111) revealed a
    problem invisible in the existing bag schema: we couldn't tell
    whether the controller was stuck in ACCEL forever (stiction) or
    rapidly chattering ACCEL↔COAST↔BRAKE (thresholds wrong) or
    transitioning cleanly. Two changes to fix the diagnosis gap and
    the stiction problem itself.
    (1) New /ball_track/diagnostic topic (Float32MultiArray)
    Published every BALL_TRACK tick. Schema:
    0: t_rel_s
    1: phase_code (-1 stale | 0 settle | 1 accel | 2 coast |
    3 brake | 4 stiction_break | 5 pid)
    2: tilt_pitch_cmd_deg
    3: tilt_roll_cmd_d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
    [ball_track_gains.yaml, digest_demo_bag.py]
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
